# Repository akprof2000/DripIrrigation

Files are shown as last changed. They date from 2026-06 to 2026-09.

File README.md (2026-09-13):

# 🌱 Капельный полив на ESP32










Автономная система капельного полива для дачного участка: 8 независимых каналов, автополив по влажности почвы, учёт расхода воды и контроль засора фильтра. Управление — полностью через Telegram-бота, без облаков и сторонних приложений ([библиотеки Alex Gyver](https://github.com/GyverLibs)).

## 📑 Оглавление

- [Возможности](#возможности)
- [Состав системы](#состав-системы)
  - [Компоненты](#компоненты)
  - [Схема подключения](#схема-подключения)
  - [Распиновка ESP32](#распиновка-esp32)
- [Установка](#установка)
- [Первый запуск](#первый-запуск)
- [Руководство пользователя](#руководство-пользователя)
  - [Команды бота](#команды-бота)
  - [Роли пользователей](#роли-пользователей)
  - [Структура меню](#структура-меню)
  - [Статус системы](#статус-системы)
  - [Типовые сценарии](#типовые-сценарии)
- [Как работает автоматика](#как-работает-автоматика)
- [Данные на SD-карте](#данные-на-sd-карте)
- [Справочник по пунктам меню](#справочник-по-пунктам-меню)
- [Обновление прошивки (OTA)](#обновление-прошивки-ota)
- [Лицензия](#лицензия)

## Возможности

- 🌿 **8 независимых каналов**: клапан + ёмкостный датчик влажности почвы на каждый
- 🤖 **Управление через Telegram** — настройка, статус, отчёты, до 8 пользователей с ролями
- 💧 **Автополив по влажности** с гистерезисом; режимы «всегда ВКЛ», «всегда ВЫКЛ», «авто», «парник»
- 🔧 **Авто-калибровка границ** датчиков: диапазон сам расширяется под реальные условия, разовые выбросы отфильтровываются
- 🌙 **Погодные блокировки**: ночь и дождь (настраиваются)
- 📟 **Датчик потока**: расход за сессию и накопленный итог, текущая скорость в статусе
- 🧽 **Контроль засора фильтра**: тревога в Telegram при падении потока ниже порога
- 💪 **Нагнетательный насос**: пусковой режим + удержание по числу открытых клапанов
- 🗑️ **Пролив дренажа** после простоя, 🚰 **заливка бака** на ночь
- 📊 **Журналы CSV** на SD-карте, графики и отчёты прямо в чате
- 📤 **OTA-обновление** прошивки файлом через Telegram

## Состав системы

### Компоненты

| Компонент | Назначение |
|---|---|
| ESP32 (DevKit) | контроллер |
| SD-карта, модуль 3.3 В | конфигурация, журналы CSV, отчёты |
| Кнопка (подтянута к земле) | сброс настроек |
| Датчик освещённости (дискретный) | определение дня/ночи |
| Датчик дождя (дискретный) | блокировка полива в дождь |
| Датчик потока YF-S201 (~450 имп/л) | учёт расхода и контроль фильтра, ставится на общую магистраль |
| DS3231 (I2C) | часы реального времени, синхронизация с NTP |
| PCF8574 (I2C, адрес 0x20) | расширитель портов для 8 клапанов |
| Релейный модуль, 8 каналов | управление клапанами полива |
| Реле ×3 | нагнетательный насос, налив ёмкости, пролив дренажа |
| 74HC4051 | аналоговый мультиплексор датчиков влажности |
| Ёмкостные датчики влажности ×8 | по одному на канал |

### Плата-носитель

Готовая печатная плата, в которую все модули вставляются в гнёзда, а внешние провода заходят на винтовые
клеммники: [описание платы](docs/hardware-carrier-board.md), [список покупок](docs/bom.md),
[пошаговая сборка](docs/assembly.md). Исходники платы и генератор — в папке `hardware/`.

### Схема подключения

Схема подключения

### Распиновка ESP32

| GPIO | Подключение | GPIO | Подключение |
|---|---|---|---|
| 2 | встроенный светодиод (индикация) | 18 | SD-карта · SCK |
| 4 | датчик освещённости | 19 | SD-карта · MISO |
| 5 | SD-карта · CS | 21 | I2C · SDA (DS3231, PCF8574) |
| 12 | 74HC4051 · S0 | 22 | I2C · SCL (DS3231, PCF8574) |
| 13 | 74HC4051 · S1 | 23 | SD-карта · MOSI |
| 14 | 74HC4051 · S2 | 25 | реле пролива дренажа |
| 15 | датчик дождя | 26 | реле нагнетательного насоса |
| 16 | кнопка сброса настроек | 27 | датчик потока YF-S201 |
| 17 | реле налива ёмкости | 33 | АЦП — сигнал мультиплексора |

## Установка

**Потребуется:** Wi-Fi сеть с выходом в интернет и созданный Telegram-бот ([инструкция по созданию бота](https://kit.alexgyver.ru/tutorials/telegram-basic/)).

1. Соберите схему
2. Скачайте исходники репозитория
3. Токен бота можно задать двумя способами (начиная с v1.8.0):
   - **ничего не делать** — при первом запуске устройство само попросит токен на странице настройки WiFi и сохранит его в EEPROM (так работают готовые бинарники из релизов);
   - **вшить в прошивку** — скопировать `secrets.example.h` в `secrets.h` и вписать токен (файл не коммитится в git).
4. Прошейте ESP32 (Arduino IDE или arduino-cli, плата `esp32`)

> ⚠️ У бота в @BotFather пропишите список команд:
> ```
> reset - сброс состояния
> control - управление поливом
> status - текущий статус
> pause - остановка статусных сообщений
> continue - продолжение получения сообщений
> ```

## Первый запуск

1. **Настройка Wi-Fi.** При первом старте устройство поднимает собственную Wi-Fi точку. Подключитесь к ней — откроется страница настройки: выберите домашнюю сеть, введите пароль и **токен бота** (если он не вшит в прошивку). После сохранения устройство перезагрузится.

   > 🔐 Токен хранится в EEPROM. Если он уже сохранён, поле «Токен» можно оставить пустым — значение не изменится. А если прошивка окажется без токена (например, взята из релизов), устройство при старте поднимет портал **только для его ввода**: сеть, пользователи и калибровки при этом сохраняются, и работа продолжится с того же места.
2. **Регистрация владельца.** Напишите боту кодовое слово со страницы настройки — вы становитесь владельцем устройства.
3. **Базовая настройка** через меню бота:
   - режимы работы клапанов → [сценарий](#типовые-сценарии);
   - калибровка датчиков влажности;
   - названия культур по каналам;
   - пороги срабатывания.
4. Система готова к работе.

> ⚠️ Запомните кодовую фразу со страницы настройки Wi-Fi — без неё не зарегистрироваться владельцем.

> 💡 Сброс к заводским настройкам: зажмите кнопку на 3 секунды сразу после старта и дождитесь трёх коротких миганий светодиода.

## Руководство пользователя

### Команды бота

| Команда | Действие | Кому доступна |
|---|---|---|
| [`/reset`](#reset) | сброс состояния меню, стартовое меню | всем зарегистрированным |
| [`/control`](#controls) | меню управления поливом | всем зарегистрированным |
| [`/status`](#status) | текущий статус системы и датчиков | всем зарегистрированным |
| [`/pause`](#pause) | остановить статусные сообщения | всем зарегистрированным |
| [`/continue`](#continue) | возобновить статусные сообщения | всем зарегистрированным |
| `/register` | запрос на регистрацию | незарегистрированным |

### Роли пользователей

| Роль | Как получить | Что доступно |
|---|---|---|
| 👑 Владелец | первым вводит кодовое слово с портала настройки | всё + OTA-обновление; не может быть понижен или удалён |
| 🎭 Администратор | назначается через «Пользователи → Повышение» | управление, настройка, пользователи, перезагрузка |
| 👤 Пользователь | отправляет `/register`, админ подтверждает | управление поливом, статус, отчёты |

### Структура меню

Пункты с пометкой 👑 видят только администраторы и владелец.

- 👑 [Перезагрузка](#restart)
- 👑 [Пользователи](#users) → [Список](#userslist) · [Повышение](#usersup) · [Понижение](#usersdown) · [Удаление](#usersdel)
- [Управление](#controls)
  - [Режим работы](#working) · [Названия](#naiming) · [Пороги срабатывания](#borders)
  - [Расход воды](#waterflow) · [Пролив дренажа](#spillage) · [Поиск датчика](#search)
- [Статус](#status)
- [Отчёты](#reports)
  - [Графики](#graphics) → [за вчера](#graphystd) · [за сегодня](#graphtd) · [за декаду](#graphdec) · [за период](#graphp) · [за дату](#graphc)
  - [Файл за вчера](#fileystd) · [Файл текущий](#filetd) · [Файл за дату](#filec)
- 👑 [Настройка](#settings)
  - [Работа ночью](#workatnight) · [Работа под дождём](#workatrain)
  - [Дельта влажности](#deltahum) · [Дельта калибровки](#deltacb)
  - [Авто-калибровка без задержки](#autocalnodelay)
  - [Насос давления](#boostpump) · [Порог фильтра](#clogthreshold) · [Фильтр прочищен](#filterclean)
  - [Таймаут Telegram](#tgtimeout)
  - [Калибровка](#calibrate) · [Ручная калибровка](#calibrateManual)
  - [Сброс настроек](#restore) · [Удаление файлов](#filesdel)

### Статус системы

`/status` показывает полную картину одним сообщением:

| Блок | Содержимое |
|---|---|
| 📅 Дата и время | текущее время системы (NTP + RTC) |
| 🌙/☀️ Погода | день или ночь, идёт ли дождь |
| 🌱 По каждому каналу | название культуры, влажность %, порог %, состояние клапана, режим работы (владельцу дополнительно — сырое значение АЦП) |
| 💧 Расход воды | литры за текущую сессию и накопленный итог |
| 🧽 Фильтр | текущая скорость потока, эталон, порог тревоги, состояние (норма/засор) |
| 💪 Насос давления | работает сейчас или нет **и почему** (пусковой режим / порог клапанов / дренаж), текущая настройка |
| 💾 Память | свободная память контроллера |

### Типовые сценарии

<details>
<summary><b>🚿 Настроить автополив канала</b></summary>

1. `Управление → Режим работы` → выбрать клапан → `🤖 АВТО` (или `🏠 А.П.` для парника — поливает и в дождь)
2. `Управление → Пороги срабатывания` → выбрать клапан → ввести порог влажности в %. Клапан откроется при влажности ниже «порог − дельта» и закроется выше «порог + дельта» — [как это работает](#полив-по-влажности)
3. `Управление → Названия` → дать каналу имя культуры («🍅 Томаты»)
</details>

<details>
<summary><b>🔧 Откалибровать датчик влажности</b></summary>

1. `Настройка → Калибровка` → выбрать датчик
2. Опустить датчик в воду → `➡️ ДАЛЕЕ` (это 100 % влажности)
3. Вытереть насухо → `➡️ ДАЛЕЕ` (это 0 %)
4. Установить датчик в почву → `✅ ЗАВЕРШИТЬ`

Если известны точные значения АЦП — `Настройка → Ручная калибровка`, ввести пару `мин,макс`.
</details>

<details>
<summary><b>🔍 Найти датчик, если неизвестен его номер</b></summary>

`Управление → Поиск датчика`: замер в воде, затем насухо — бот назовёт номер датчика с наибольшей разницей показаний.
</details>

<details>
<summary><b>💧 Посмотреть расход воды</b></summary>

`Управление → Расход воды` — литры за текущую сессию полива и накопленный итог, там же кнопка стирания данных. Текущая скорость потока — в `Статусе`.
</details>

<details>
<summary><b>🧽 Пришла тревога «засорился фильтр»</b></summary>

1. Перекройте воду и прочистите фильтр на магистрали
2. `Настройка → Фильтр прочищен` — система заново замерит скорость «чистого» потока

Подробнее о механизме — [Контроль засора фильтра](#учёт-расхода-и-контроль-засора-фильтра).
</details>

<details>
<summary><b>💪 Настроить насос повышения давления</b></summary>

`Настройка → Насос давления`:
- число **1–8** — держать насос включённым, пока открыто столько клапанов и больше;
- **9** — не держать, только пусковые 30 секунд при каждом открытии клапана.

Текущее состояние насоса и причина — в `Статусе`. [Диаграмма работы](#насос-повышения-давления).
</details>

<details>
<summary><b>📈 Получить графики и файлы измерений</b></summary>

`Отчёты → Графики` — график влажности по каналам за вчера/сегодня/декаду/период/дату.
`Отчёты → Файл...` — бот пришлёт CSV-файл с измерениями ([формат](#данные-на-sd-карте)).
</details>

<details>
<summary><b>🔕 Отключить уведомления на время</b></summary>

Команда `/pause`, вернуть — `/continue` (действует до перезагрузки устройства).
</details>

<details>
<summary><b>👥 Добавить нового пользователя</b></summary>

1. Новый человек пишет боту `/register`
2. Администраторам приходит запрос со ссылкой-командой — админ нажимает её, человек зарегистрирован как «пользователь»
3. При необходимости повысить: `Пользователи → Повышение`
</details>

<details>
<summary><b>📤 Обновить прошивку по воздуху</b></summary>

Владелец отправляет в чат файл `DripIrrigation.ino.bin` — устройство обновится и перезагрузится. [Подробнее](#обновление-прошивки-ota).
</details>

## Как работает автоматика

Общая картина: раз в минуту выполняется цикл полива, а фоновые задачи (бот, насос, контроль потока, дренаж, связь) работают непрерывно.

Алгоритм работы

### Полив по влажности

Раз в минуту система опрашивает все 8 датчиков (медиана из 9 замеров АЦП — устойчиво к помехам) и для каждого канала в режиме «авто» сравнивает влажность с порогом. Гистерезис (зона ±Δ вокруг порога) исключает дребезг — клапан не щёлкает туда-сюда при колебаниях показаний:

Автополив с гистерезисом

### Авто-калибровка границ

Со временем реальный диапазон датчика уходит за границы, заданные при калибровке: почва после ливня оказывается влажнее «воды» из стакана, а в засуху — суше «сухого» замера. Тогда проценты упираются в 0 или 100 и перестают что-либо показывать.

Система расширяет границы сама: если показание вышло за границу, она отодвигается до этого значения **с запасом в дельту калибровки**. Границы только расширяются, сужения нет — сузить можно лишь перекалибровкой.

Авто-калибровка границ

Два предохранителя:

- **Разовые выбросы игнорируются.** Граница двигается, только если превышение держится **3 минутных замера подряд**. Один сбойный отсчёт АЦП (наводка, плохой контакт) обнуляет счётчик и ничего не портит. Внутри окна подтверждения берётся самое мягкое из превышений, чтобы выброс не утянул границу. Отключается настройкой [«Авто-калибровка без задержки»](#autocalnodelay).
- **Во время калибровки функция выключена.** Пока открыт диалог калибровки или поиска датчика, датчик держат в воде или на воздухе — такие показания нельзя принимать за рабочие, иначе система «выучит» калибровочные экстремумы как норму.

Новые границы сохраняются на SD-карту автоматически.

### Аварийный режим при неисправном оборудовании

Платы (RTC, SD-карта, расширитель клапанов PCF8574) инициализируются **неблокирующе**: если узел не отвечает, система всё равно завершает загрузку и поднимает бота. Неисправность приходит в чат с пояснением последствий — не нужно ехать к устройству и подключаться кабелем, чтобы понять, что случилось.

Пока неисправность не устранена:

- **полив остановлен** — работать с неисправным железом опасно;
- насос, дренаж и залив бака **выключены напрямую по пинам** (не через возможно мёртвый PCF8574);
- интерфейс бота свёрнут до отчёта и **единственной кнопки «Перезагрузка»** — починив контакт, систему можно поднять прямо из чата.

### Погодные блокировки

Ночью и в дождь полив останавливается, если это запрещено в настройках. Исключения: каналы «всегда ВКЛ» и режим «парник» продолжают полив под дождём (но не ночью). При наступлении ночи подаётся сигнал заполнения ёмкости — за ночь вода прогреется к утреннему поливу.

### Насос повышения давления

При открытии любого клапана насос включается минимум на 30 секунд для стабилизации давления. Дальше — по настройке: либо выключается, либо продолжает работать, пока открыто N и более клапанов:

Работа насоса

Пролив дренажа также идёт с включённым насосом. Фактическое состояние насоса и причина всегда видны в `Статусе`.

### Пролив дренажа

Если полив не шёл более 5 часов, при открытии первого клапана автоматически запускается пролив дренажа на 12 секунд — сброс накопившейся ржавчины из труб, чтобы не засорялись форсунки. Ручной запуск: `Управление → Пролив дренажа`.

### Учёт расхода и контроль засора фильтра

На общей магистрали стоит импульсный датчик потока (YF-S201). Система считает расход за сессию полива и накопленный итог, а также непрерывно следит за скоростью потока:

Контроль засора фильтра

Ключевые детали алгоритма:

- после открытия клапана трубы наполняются — поток кратковременно завышен, поэтому система **дожидается стабилизации** и только потом замеряет;
- эталон «чистого» фильтра запоминается автоматически (разовые выбросы отфильтровываются — новое значение должно продержаться несколько минут);
- замеры при работающем пусковом насосе и заливке бака не учитываются;
- тревога подтверждается несколькими окнами замера подряд и повторяется не чаще раза в сутки.

## Данные на SD-карте

```
/configuration.dat      — конфигурация системы (бинарная)
/ГГГГ/ММ/ДД.csv         — журнал измерений за день
```

Каждую минуту в CSV дописывается по строке на канал:

| Колонка | Описание |
|---|---|
| `UnixTime` | метка времени UNIX |
| `DateTime` | дата и время в читаемом виде |
| `Index` | номер канала (1–8) |
| `Title` | название культуры |
| `Humidity` | влажность, % |
| `Valve` | состояние клапана: 1 — открыт, 0 — закрыт |
| `Border` | порог срабатывания, % |
| `Night` | ночь: 1/0 |
| `Rain` | дождь: 1/0 |

Файлы за прошлые годы можно удалить из бота: `Настройка → Удаление файлов`.

## Справочник по пунктам меню

#### /reset — сброс состояния
Сбрасывает состояние меню и выводит стартовое меню

#### /status · меню «Статус»
Полный статус системы — [расшифровка блоков](#статус-системы)

#### /pause — остановка статусных сообщений
Останавливает сообщения о событиях на устройстве (действует до перезагрузки)

#### /continue — продолжение получения сообщений
Возобновляет сообщения о событиях

#### 👑 Перезагрузка
Перезапускает устройство (с подтверждением)

#### 👑 Пользователи

- **Список** — зарегистрированные пользователи (идентификаторы и роли)
- **Повышение** — Пользователь → Администратор
- **Понижение** — Администратор → Пользователь (владельца понизить нельзя)
- **Удаление** — удаление пользователя (владельца удалить нельзя)

#### Управление

- **Режим работы** — режим каждого клапана: ✅ постоянно включен · ⛔ постоянно выключен · 🤖 автоматический по влажности · 🏠 парник (авто, работает и при дожде); кнопка «Установить для всех»
- **Названия** — имя выращиваемой культуры для каждого канала
- **Пороги срабатывания** — порог влажности каждого клапана в %
- **Расход воды** — литры за сессию и накопленный итог; стирание данных
- **Пролив дренажа** — ручной запуск пролива (12 секунд)
- **Поиск датчика** — определить номер датчика по замерам в воде и насухо

#### Отчёты

- **Графики**
  - **за вчера** — почасовой график влажности по каналам
  - **за сегодня** — почасовой график за текущий день
  - **за декаду** — последние 10 дней, 6 значений в сутки
  - **за период** — от 1 до 60 дней, `целое(60 / кол-во дней)` значений в сутки
  - **за дату** — график за выбранный день
- **Файл за вчера** — CSV-файл с измерениями за вчера
- **Файл текущий** — CSV-файл за сегодня
- **Файл за дату** — CSV-файл за выбранный день

#### 👑 Настройка

- **Работа ночью** — разрешить/запретить полив ночью
- **Работа под дождём** — разрешить/запретить полив в дождь
- **Дельта влажности** — половина гистерезиса вокруг порога, % (0–100, по умолчанию 5)
- **Дельта калибровки** — запас у границ калибровки датчиков, ед. АЦП (0–2048, по умолчанию 15). Используется и как запас при [авто-калибровке границ](#авто-калибровка-границ)
- **Авто-калибровка без задержки** — двигать границу сразу по первому замеру за ней. По умолчанию **выключено**: граница двигается, только если превышение держится 3 замера подряд (3 мин) — так одиночный выброс АЦП не портит калибровку. Включайте, только если нужна мгновенная реакция
- **Насос давления** — держать насос при ≥ N открытых клапанах (1–8); 9 — только пусковые 30 с
- **Порог фильтра** — % от скорости «чистого» фильтра, ниже которого тревога (10–90, по умолчанию 50)
- **Фильтр прочищен** — сброс эталона после чистки, система замерит его заново
- **Таймаут Telegram** — через сколько секунд без связи считать её потерянной (120–3600, по умолчанию 180). Увеличьте, если приходит много сообщений о кратковременных обрывах связи
- **Калибровка** — пошаговая калибровка датчика: замер в воде, затем насухо
- **Ручная калибровка** — ввод граничных значений АЦП парой `мин,макс`
- **Сброс настроек** — возврат к заводским установкам
- **Удаление файлов** — удаление архивов измерений за прошлые годы

## Обновление прошивки (OTA)

1. Возьмите готовый файл со [страницы релизов](https://github.com/akprof2000/DripIrrigation/releases) (собирается автоматически в GitHub Actions) — или соберите сами (`Скетч → Экспорт бинарного файла` в Arduino IDE):
   - `DripIrrigation.ino.bin` — обычный (~1.3 МБ);
   - `DripIrrigation.ino.bin.gz` — сжатый (~0.8 МБ), удобнее по мобильному интернету — устройство распакует его само.
2. Отправьте файл в чат боту **от имени владельца**
3. Устройство скачает файл, обновится и перезагрузится; после старта придёт сообщение «🚀 Система запущена! Прошивка vX.Y.Z»

> 💡 Имя файла может содержать суффикс копии, который добавляет Windows при повторном скачивании: `DripIrrigation.ino.bin (2).gz` и `DripIrrigation.ino (2).bin` тоже принимаются — переименовывать не нужно.

> 🔁 Если пришло `OTA Fetch Error` — файл не удалось **скачать** (обычно не хватило памяти на защищённое соединение после долгой работы). Прошивка при этом не пострадала: просто отправьте файл ещё раз, а если повторяется — перезагрузите систему через меню и повторите.

> ✅ Проверить версию можно в любой момент — она указана в шапке `/status`. Если после OTA номер не изменился, обновление не применилось.

> 🛡️ OTA безопасен: прошивка пишется в неактивный раздел, загрузка переключается только при валидном образе. Неудачное обновление оставит устройство на прежней прошивке (не «кирпич»).

> ⚠️ Прошивка должна быть собрана под ту же схему разделов (partition scheme), что и установленная.

> 🏷️ Версия задаётся в `version.h` (`FW_VERSION`) и должна совпадать с git-тегом релиза.

## Сторонние компоненты

- Библиотеки [Alex Gyver](https://github.com/GyverLibs): FastBot2, GyverNTP, GyverDS3231, FileData, CharDisplay и зависимости
- [uzlib](https://github.com/pfalcon/uzlib) (zlib-лицензия) — потоковая распаковка gzip для OTA из `.gz` (файлы `uzlib.h`, `tinflate.c`, `tinfgzip.c`, `crc32.c`, `adler32.c` и заголовки)
- PCF8574 library (Renzo Mischianti)

## Лицензия

[WTFPL 2.0](LICENSE) — делайте с этим кодом что хотите, без каких-либо условий.

Исключение: файлы `uzlib.h`, `tinflate.c`, `tinfgzip.c`, `crc32.c`, `adler32.c`,
`defl_static.h`, `tinf.h`, `tinf_compat.h`, `uzlib_conf.h` — это стороннее
заимствование ([uzlib](https://github.com/pfalcon/uzlib)) и они остаются под
своей zlib-лицензией; уведомления об авторстве в них сохранены.

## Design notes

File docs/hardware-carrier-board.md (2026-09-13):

# 🧩 Плата-носитель DripIrrigation

Контроллер собирается «из кубиков»: все сложные узлы покупные, а связывает их **одна плата-носитель**,
в которую модули **вставляются в гнёзда**. На плате нет SMD, нет проводов «навесом», и ничего не отваливается:
модули сидят в гнёздах и прижаты стойками, все внешние провода — в винтовых клеммниках с обжатыми
наконечниками, в том числе провода к релейным модулям.

Плата **уже спроектирована**: файл [`hardware/DripCarrier.kicad_pcb`](../hardware/DripCarrier.kicad_pcb)
проверен DRC в KiCad 10: ошибок и неразведённых цепей нет. Раздел [5](#5-заказ-платы) — как заказать.

Распиновка ESP32 — из `pins.h` / README, без изменений.

Полный список покупок со ссылками — [bom.md](bom.md). Пошаговая сборка с картинками — [assembly.md](assembly.md).

---

## 1. Из чего состоит

Структура

### Выбранные модули

| Что | Какой именно | Куда ставится |
|---|---|---|
| ESP32 | DevKitC **38 pin**, Type-C, CP2102, вариант ESP-32U | гнездо U1 (2 гребёнки 1×19) |
| Часы | модуль DS3231 с держателем батарейки, выводы 32K · SQW · SCL · SDA · VCC · GND | гнездо J9 (1×6) |
| SD-карта | шилд Micro SD формата D1 mini, два ряда по 8 выводов | гнездо J8 (2×8) |
| Реле клапанов | красный модуль H/L, **8 каналов, 5 В**, 108,5×50 мм | клеммы J6 |
| Реле насоса | красный модуль H/L, **1 канал, 5 В**, 51×25,5 мм | клеммы J7 |
| Реле налива и дренажа | красный модуль H/L, **2 канала, 5 В** | клеммы J5 |
| Датчик света | модуль фоторезистора на LM393, выход DO; фоторезистор выпаян и вынесен наружу | гнездо U6 (1×3), фоторезистор на клеммник J12 |
| Датчики влажности ×8 | ёмкостные Capacitive Soil Moisture Sensor v2.0, кабель 3 провода | клеммники S1…S8 |

### Остальное

| Что | Что искать в магазине | Куда ставится |
|---|---|---|
| PCF8574P (микросхема DIP-16) | `PCF8574P DIP` | панелька U4 |
| 74HC4051 (микросхема DIP-16) | `CD74HC4051E DIP` / `SN74HC4051N` | панелька U5 |
| Импульсный DC-DC 12→5 В, 2 А, формат TO-220 | `K7805-2000R3` (3 pin: IN GND OUT) | U2 |
| Импульсный DC-DC 5→3,3 В, 1 А, формат TO-220 | `K7803-1000R3` (3 pin: IN GND OUT) | U3 |
| Антенна 2,4 ГГц с кабелем IPEX | `2.4G antenna IPEX u.FL` | к ESP-32U, выводится из корпуса |
| Датчик дождя Rain Seer, проводной, с сухим контактом | [товар](https://aliexpress.ru/item/1005004442230539.html?sku_id=12000029194430427) | клеммник J11 (2 провода) |
| Расходомер | `YF-S201` | клеммник J10 |
| Источник питания 12 В, не менее 5 А | любой источник постоянного тока 12 В | клеммник J1 |

### Замечания по выбранным модулям

* **ESP-32U** без встроенной антенны, у неё разъём IPEX. Без внешней антенны Wi-Fi почти не работает.
  Зато антенну можно вывести наружу корпуса, подальше от реле, и связь на участке будет лучше.
* **Ряды ESP32 38 pin** на плате разнесены на 25,4 мм. Перед заказом платы измерьте свой модуль штангенциркулем.
* **DS3231** у этого продавца, по отзывам, может прийти в варианте DS3231M. Он чуть менее точный, но часы
  всё равно синхронизируются по NTP, так что это не важно.
* **Угловые штыри у DS3231 и датчика света** нужно заменить прямыми. Модули лежат параллельно плате над
  своими гнёздами J9 и U6, штыри смотрят вниз. Выпаяйте угловую гребёнку и впаяйте прямую той же длины со
  стороны деталей модуля так, чтобы штыри выходили с обратной стороны. Если оставить угловые штыри, модуль
  встанет вертикально, будет качаться и не поместится под крышку.
* **SD-шилд D1 mini** сидит на 16 выводах и держится в гнезде крепче маленьких 6-контактных модулей.
  Используются только D5 (SCK), D6 (MISO), D7 (MOSI), D8 (CS), 3V3 и G.
* **Датчики влажности** бывают с микросхемой TLC555 и с NE555. Посмотрите маркировку восьминогой
  микросхемы на каждом датчике. TLC555 работает от 3,3 В. NE555 от 3,3 В не запускается и выдаёт 0 В,
  таким датчикам нужно 5 В. Питание всех восьми датчиков выбирается перемычкой **JP1** на плате:
  джампер на 3V3 или на 5V. Выход датчика даже при 5 В не превышает примерно 3 В, АЦП ESP32 это выдерживает.
  Не смешивайте на одной плате датчики с разными микросхемами. После смены питания датчики нужно
  перекалибровать.
* **Датчик света** стоит на плате в гнезде U6, а наружу выносится только фоторезистор. Как подготовить модуль:
  1. Выпаять фоторезистор с модуля.
  2. В освободившиеся отверстия впаять два штырька 2,54 мм.
  3. Соединить эти штырьки со штырьками JL1 на плате коротким кабелем на два провода с колодками на концах.
  4. Выносной фоторезистор подключить двумя проводами к клеммнику J12. Выводы фоторезистора закрыть термоусадкой.

  Порядок выводов гнезда U6 рассчитан на VCC · GND · DO. Сверьте с подписями на своём модуле перед пайкой гнезда.
* **Датчик дождя** механический: шайбы набухают от воды и переключают контакт. Для платы это кнопка на двух
  проводах, клеммник J11. Резистор R7 10 кОм подтягивает вход GPIO15 к 3,3 В, R8 1 кОм и конденсатор C4 100 нФ
  защищают вход от наводок на длинном кабеле. Прошивка считает дождём низкий уровень, поэтому контакт
  должен **замыкаться при дожде**. Проверьте мультиметром до подключения: сухой датчик — контакт разомкнут,
  датчик с мокрыми шайбами — замкнут. Если у датчика три провода, используйте общий и нормально разомкнутый.
  Если контакт работает наоборот, скажите: поменяю логику в прошивке.
* **PCF8574 и 74HC4051 взяты микросхемами**: у модулей разных продавцов разный порядок выводов,
  а у DIP-микросхемы он стандартный.

> ⚠️ Подписи выводов ESP32, SD-шилда и DS3231 нанесены на шелкографию платы. Перед пайкой гнёзд
> приложите свои модули и сверьте подписи — у клонов бывает зеркальный порядок.

---

## 2. Питание и реле

Питание

* Три шины: **12 В** (клапаны, насос, вход DC-DC), **5 В** (ESP32, все реле, расходомер),
  **3,3 В** (логика и датчики).
* На входе — предохранитель F1 5 А и P-MOSFET Q1 от переполюсовки. Насос — через отдельный F2 3 А.
  MOSFET вместо диода взят из-за тока: при 4–5 А диод Шоттки терял бы около 3 Вт и требовал радиатор,
  а на канале IRF4905 теряется 0,5 Вт, и клапаны получают полные 12 В. TVS-диод D2 на шине 12 В гасит
  выбросы от катушек клапанов и насоса при размыкании реле.
* Дорожки 12 В шириной 2 мм (до 5 А), 5 В — 1,2 мм, земля — 1 мм плюс сплошная заливка на нижней стороне.
* Вывод 3V3 модуля ESP32 к плате **не подключён**: свой стабилизатор модуля питает только ESP32,
  а вся периферия — от U3. Два стабилизатора на одной шине мешали бы друг другу.
* Каждый релейный модуль получает +5 В и GND со своей клеммы на плате. Одиннадцать катушек по 70 мА
  плюс ESP32 дают до 1,2 А, поэтому преобразователь 12→5 В нужен не слабее 2 А.
* **Преобразователи U2 и U3 — только импульсные** (K7805-2000R3 и K7803-1000R3). У них КПД около 90%:
  на 12→5 В при 1,2 А теряется меньше 1 Вт, радиатор не нужен. Линейный L7805 в таком же корпусе при том же
  токе рассеивал бы около 8 Вт и без большого радиатора перегрелся бы — его ставить нельзя.
* Силовые провода клапанов и насоса идут **к контактам реле**, а не через плату. Плата отдаёт на них
  +12 В с клеммников J3 (общая шина COM клапанов) и J4 (насос, после F2).

### Перемычки H/L на реле

Уровень включения задан прошивкой, поэтому перемычки ставятся так:

| Модуль | Чем управляется | Как включает прошивка | Перемычка |
|---|---|---|---|
| 8 каналов, клапаны | PCF8574, выходы P0…P7 | низким уровнем | **L** |
| 1 канал, насос | ESP32 GPIO26 | высоким уровнем | **H** |
| 2 канала, налив и дренаж | ESP32 GPIO17 и GPIO25 | высоким уровнем | **H** |

**Клапаны в режиме L работают надёжно.** PCF8574 хорошо тянет выход к земле, а в выключенном состоянии
почти не отдаёт ток, так что реле не срабатывает ложно. При включении питания PCF8574 держит выходы
в единице, клапаны закрыты.

**Насос, налив и дренаж в режиме H нужно проверить до сборки.** Модуль рассчитан на сигнал 5 В, а ESP32
выдаёт 3,3 В. Многие экземпляры срабатывают и так, но не все. Проверка занимает минуту:
подайте на модуль 5 В, перемычку поставьте в H, а на вход IN подайте 3,3 В с платы ESP32.
Реле должно щёлкнуть.

Если реле от 3,3 В не срабатывает, есть два выхода:

1. Перевести перемычку в **L** и инвертировать в прошивке управление насосом, наливом и дренажом.
   В режиме L 3,3 В на входе реле надёжно выключает, а 0 В надёжно включает.
2. Взять эти модули в варианте **12 В**: вход в режиме H у них тоже рассчитан на логику, но питание
   катушек идёт от 12 В и разгружает шину 5 В. Проверять срабатывание от 3,3 В всё равно нужно.

---

## 3. Плата

Двухсторонняя, 150×110 мм, все детали выводные. Сгенерирована скриптом
[`hardware/gen_pcb.py`](../hardware/gen_pcb.py), который расставляет компоненты, проверяет, что корпуса
не пересекаются, задаёт цепи и трассирует дорожки. Верх — дорожки в основном горизонтальные,
низ — вертикальные, снизу ещё заливка земли.

**Все детали ставятся на верхнюю сторону и паяются только с нижней.** Переворачивать плату в процессе
сборки не нужно.

**Расстановка сделана под монтаж проводов:**

* Все клеммники стоят по краям платы: сверху питание 12 В и управление реле, справа расходомер, свет и дождь,
  снизу датчики влажности. Ставьте клеммники отверстием для провода наружу, к краю платы.
* Высокие детали — предохранители, конденсаторы, модули DC-DC — стоят вторым рядом, внутри платы.
  Они не мешают заводить провода и крутить винты.
* Проверка пересечений учитывает реальные размеры модулей, а не только их гребёнки. Модуль DS3231
  размером около 38×22 мм показан на плате пунктиром и не накрывает соседние детали. Перед заказом
  измерьте свой модуль: если он крупнее, его контур нужно поправить в генераторе.

Верх

Низ

### Разъёмы к реле

У каждого релейного модуля своя клеммная колодка: питание +5 В, земля и его сигналы. Питание не
передаётся с модуля на модуль, поэтому отключение одного не обесточивает другие.

| Клеммник | Модуль | 1 | 2 | 3 | 4 | 5…10 |
|---|---|---|---|---|---|---|
| J6, 10P | реле 8 каналов | +5 В → DC+ | GND → DC− | IN1 | IN2 | IN3…IN8 |
| J7, 3P | реле 1 канал | +5 В → DC+ | GND → DC− | насос → IN | — | — |
| J5, 4P | реле 2 канала | +5 В → DC+ | GND → DC− | налив → IN1 | дренаж → IN2 | — |

### Что куда подключается

**Питание платы — клеммник J1 в левом верхнем углу.** Источник 12 В, не менее 5 А. Контакт с квадратной
площадкой — **+12 В**, второй — **GND (минус)**. Перепутанная полярность не сожжёт плату: MOSFET Q1 просто не
откроется, и плата не включится.

**Клеммники — внешние провода**

| Обозначение | Подпись на плате | Контакты по порядку, от квадратной площадки | Что подключается |
|---|---|---|---|
| J1 | 12V IN | +12 В · GND | источник питания 12 В, 5 А |
| J3 | 12V VALVES | +12 В · GND | +12 В на общий COM всех 8 реле клапанов; GND — к второму проводу клапанов |
| J4 | 12V PUMP | +12 В (после F2) · GND | +12 В на COM реле насоса; GND — к насосу |
| J6 | RELAY 8 | +5 В · GND · IN1 … IN8 | модуль реле 8 каналов: DC+, DC−, входы IN1…IN8 |
| J7 | RELAY 1 | +5 В · GND · PUMP | модуль реле 1 канал: DC+, DC−, IN |
| J5 | RELAY 2 | +5 В · GND · FILL · DRAIN | модуль реле 2 канала: DC+, DC−, IN1 налив, IN2 дренаж |
| J10 | FLOW | +5 В · GND · сигнал | расходомер YF-S201: красный, чёрный, жёлтый |
| J12 | LDR | вывод 1 · вывод 2 | выносной фоторезистор, полярности нет |
| J11 | RAIN SW | сигнал · GND | датчик дождя, сухой контакт: общий и нормально разомкнутый провод |
| S1 … S8 | SOIL 1 … 8 | питание · GND · сигнал | датчики влажности: VCC, GND, AOUT |

Питание датчиков влажности на S1…S8 — 3,3 или 5 В, выбирается джампером JP1.

**Гнёзда и панельки — модули и микросхемы**

| Обозначение | Что вставляется |
|---|---|
| U1 | ESP32 DevKitC 38 pin, USB вниз |
| J8 | шилд microSD D1 mini |
| J9 | модуль часов DS3231 |
| U6 | модуль датчика света LM393 |
| U4 | микросхема PCF8574P |
| U5 | микросхема 74HC4051 |
| U2 | импульсный DC-DC 12→5 В |
| U3 | импульсный DC-DC 5→3,3 В |

**Остальные детали на плате**

| Обозначение | Деталь | Назначение |
|---|---|---|
| F1 | предохранитель 5 А | защита всего питания 12 В |
| F2 | предохранитель 3 А | защита цепи насоса |
| Q1 | P-MOSFET IRF4905 | защита от переполюсовки, без падения напряжения |
| R9 | 10 кОм | затвор Q1 к земле |
| D2 | TVS P6KE18CA | гасит выбросы на шине 12 В |
| C5, C6 | 100 нФ | развязка PCF8574 и 74HC4051 |
| R10, R11 | 4,7 кОм | подтяжки I2C, шина работает и без модуля часов |
| C1 | 1000 мкФ | фильтр 12 В |
| C2, C3 | 100 мкФ | фильтры 5 В и 3,3 В |
| C4 | 100 нФ | фильтр входа датчика дождя |
| R1, R2, R3 | 10 кОм | подтяжка выбора канала мультиплексора |
| R4 | 10 кОм | подтяжка кнопки к земле; кнопка замыкает вход на 3,3 В |
| R5, R6 | 10 кОм, 33 кОм | делитель сигнала расходомера: с внутренней подтяжкой 10 кОм в YF-S201 даёт около 3,1 В |
| R7 | 10 кОм | подтяжка датчика дождя |
| R8 | 1 кОм | защита входа датчика дождя |
| SW1 | кнопка | сброс настроек: замыкает GPIO16 на 3,3 В, как в прошивке |
| JP1 | штыри 1×3 и джампер | питание датчиков влажности: 3V3 или 5V |
| JL1 | штыри 1×2 | кабель к площадкам фоторезистора на модуле U6 |

### Диаметры отверстий

Отверстия подобраны под выводы деталей с запасом 0,2–0,4 мм. Таблица диаметров нанесена на шелкографию
платы слева внизу, под ESP32.

| Детали | Вывод детали | Отверстие | Площадка |
|---|---|---|---|
| Клеммники 5,08 мм, все | около 1,0 мм | **1,3 мм** | 2,6 мм |
| Держатели предохранителей F1, F2 | плоский, до 1,2 мм | **1,5 мм** | 2,8 мм |
| TVS P6KE18CA (D2) | до 1,0 мм | **1,5 мм** | 2,8 мм |
| MOSFET Q1, выводы разведены на 5,08 мм | 0,9 мм | 1,1 мм | 2,0 мм |
| Гнёзда модулей ESP32, SD, DS3231, свет; штыри JP1, JL1 | 0,64 мм квадрат | 1,0 мм | 1,6 мм |
| DC-DC U2, U3, штыри | до 0,8 мм | 1,0 мм | 1,6 мм |
| Кнопка SW1 | 0,7 мм плоский | 1,0 мм | 1,7 мм |
| Конденсатор 1000 мкФ (C1) | 0,6 мм | 1,1 мм | 2,0 мм |
| Панельки DIP-16, конденсаторы 100 мкФ | 0,5 мм | 0,9 мм | 1,6–1,7 мм |
| Резисторы, керамические C4, C5, C6 | 0,6 мм | 0,8 мм | 1,6 мм |
| Крепёжные отверстия М3 | — | 3,2 мм, без металлизации | — |

Перед пайкой сверьте с реальными деталями: вывод держателя предохранителя и диода штангенциркулем.

### Что паяется

| Поз. | Деталь | Что искать | Кол-во |
|---|---|---|---|
| U1 | гребёнка-мама 1×19, machined | `machined female header 2.54 1x20` (отрезать) | 2 |
| J8 | гребёнка-мама 1×8 | `female header 2.54 1x8` | 2 |
| J9 | гребёнка-мама 1×6 | `female header 2.54 1x6` | 1 |
| U6 | гребёнка-мама 1×3 под модуль датчика света | `female header 2.54 1x3` | 1 |
| JL1 | штыри 1×2 к площадкам фоторезистора модуля | `pin header 2.54` | 1 |
| U4, U5 | панелька DIP-16 | `DIP-16 IC socket` | 2 |
| J1, J3, J4, J11, J12 | клеммник 5,08 мм 2P | `KF301-2P` или разъёмный `KF2EDG 5.08 2P` | 5 |
| J6 | клеммник 5,08 мм 10P | `KF2EDG 5.08 10P` (или 5 шт. 2P в ряд) | 1 |
| J5 | клеммник 5,08 мм 4P | `KF2EDG 5.08 4P` | 1 |
| J7, J10, S1–S8 | клеммник 5,08 мм 3P | `KF301-3P` / `KF2EDG 5.08 3P` | 10 |
| R7 | 10 кОм 0,25 Вт, подтяжка входа датчика дождя | | 1 |
| R8 | 1 кОм 0,25 Вт, защита входа датчика дождя | | 1 |
| C4 | 100 нФ керамический, шаг 5 мм | | 1 |
| F1, F2 | держатель предохранителя 5×20 + вставки 5 А, 3 А | `5x20 PCB fuse holder` | 2 |
| Q1 | P-MOSFET 55 В 74 А, TO-220 | `IRF4905` | 1 |
| D2 | TVS двунаправленный 18 В, 600 Вт | `P6KE18CA` | 1 |
| C1 | 1000 мкФ 16 В, шаг 5 мм | | 1 |
| C2, C3 | 100 мкФ 16 В, шаг 2,5 мм | | 2 |
| R1–R4, R9 | 10 кОм 0,25 Вт (подтяжки S0…S2, кнопки и затвора Q1 вниз) | | 5 |
| R10, R11 | 4,7 кОм 0,25 Вт (подтяжки I2C) | | 2 |
| C5, C6 | 100 нФ керамика, шаг 5 мм (развязка) | | 2 |
| R5, R6 | 10 кОм и 33 кОм (делитель расходомера) | | 1+1 |
| SW1 | кнопка тактовая 6×6 | | 1 |
| JP1 | штыри 1×3 + джампер (питание датчиков влажности 3,3 / 5 В) | `pin header 2.54 1x3` + `jumper cap` | 1 |
| — | стойки М3 пластик 10 мм, винты | | 16 |

Полная таблица цепей — [`hardware/netlist.md`](../hardware/netlist.md).

### Цепи, которые легко упустить

* GPIO12 (S0 мультиплексора) — strapping-пин ESP32, при старте должен быть низким: R1…R3 тянут S0…S2 к земле.
* Выход YF-S201 пятивольтовый и внутри подтянут к 5 В резистором 10 кОм: вместе с R5/R6 на GPIO27 получается
  около 3,1 В. Если у вашего экземпляра расходомера на выходе меньше 2,6 В, замените R6 на 10 кОм к 3,3 В.
* PCF8574: A0…A2 на GND → адрес 0x20, как в прошивке. 74HC4051: E и VEE на GND.
* На DS3231 и модулях датчиков подтяжки I2C и компараторы уже есть — на плате их нет специально.

---

## 4. Компоновка в корпусе

Корпус

* Корпус `ABS junction box 250×200×80 IP65`. Плата и все три релейных модуля на стойках М3.
* Провода от J5, J6 и J7 к реле обжаты наконечниками НШВИ и зажаты винтами с обеих сторон.
  Если у 8-канального модуля вход сделан гребёнкой, а не клеммами, используйте одну колодку 1×10
  с обжатыми контактами, а не десять отдельных проводов.
* Ввод кабелей — гермовводы PG9; концы проводов обжаты наконечниками НШВИ (клещи `HSC8 6-4`).
* Антенна ESP-32U выводится через стенку корпуса разъёмом SMA.

---

## 5. Заказ платы

Файлы для завода собираются одной командой через KiCad 10 в Docker. Скрипт заливает землю, прогоняет DRC
и складывает Gerber-файлы со сверловкой в архив `hardware/DripCarrier-gerbers.zip`.

```bash
bash hardware/kicad-docker.sh
```

Этот архив загружается на JLCPCB или PCBWay: 2 слоя, толщина 1,6 мм, 5 штук. Стоит около 5–10 $ плюс доставка.

Хотите поменять расположение — правьте координаты в `hardware/gen_pcb.py` и запускайте его снова.
Он проверит пересечения, перетрассирует плату и обновит картинки. После этого снова запустите скрипт Docker.

```bash
python hardware/gen_pcb.py
```

---

## 6. Сборка и проверка

1. Проверить реле насоса, налива и дренажа на срабатывание от 3,3 В, как описано в разделе 2.
2. Впаять клеммники, гнёзда, панельки, резисторы, диод, конденсаторы, держатели предохранителей, кнопку.
   Модули пока не вставлять.
3. Подать 12 В на J1. Проверить: +12 на J3, 5,0 В между контактами 1 и 2 клеммника J6,
   3,3 В на выводе 16 панельки U4.
4. Вставить ESP32 с антенной, прошить, дождаться Wi-Fi.
5. Вставить PCF8574, 74HC4051, DS3231, SD — в логе прошивки должны появиться RTC и расширитель.
6. Выставить перемычки H/L, подключить реле 8 каналов к J6, 1 канал к J7, 2 канала к J5, щёлкать каналами из меню бота.
7. Обжать и подключить датчики и клапаны, откалибровать датчики влажности.

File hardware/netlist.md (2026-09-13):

# Таблица цепей платы-носителя

Сгенерировано `gen_pcb.py`. Формат: `Компонент.пин`.

| Цепь | Выводы |
|---|---|
| `+12V` | J3.1, Q1.3, D2.1, C1.1, U2.1, F2.1 |
| `+3V3` | U3.3, C3.1, U4.16, U5.16, J8.3V3, J9.5, SW1.3, SW1.4, C5.1, C6.1, R10.2, R11.2, JP1.1, U6.1, R7.2 |
| `+5V` | J6.1, J7.1, J5.1, U2.3, C2.1, U3.1, U1.5V, JP1.3, J10.1 |
| `12V_F` | F1.2, Q1.2 |
| `12V_PUMP` | J4.1, F2.2 |
| `12V_RAW` | J1.1, F1.1 |
| `GND` | J1.2, J3.2, J4.2, J6.2, J7.2, J5.2, R9.2, D2.2, C1.2, U2.2, C2.2, U3.2, C3.2, U1.GND, U1.GND2, U1.GND3, U4.1, U4.2, U4.3, U4.8, U5.6, U5.7, U5.8, J8.G, J9.6, R4.2, R1.2, R2.2, R3.2, R6.2, C5.2, C6.2, J10.2, U6.2, J11.2, C4.2, S1.2, S2.2, S3.2, S4.2, S5.2, S6.2, S7.2, S8.2 |
| `SENS_V` | JP1.2, S1.1, S2.1, S3.1, S4.1, S5.1, S6.1, S7.1, S8.1 |
| `ADC` | U1.D33, U5.3 |
| `BTN` | U1.D16, SW1.1, SW1.2, R4.1 |
| `DRAIN` | J5.4, U1.D25 |
| `FILL` | J5.3, U1.D17 |
| `FLOW` | U1.D27, R5.2, R6.1 |
| `FLOW_IN` | R5.1, J10.3 |
| `LDR_A` | J12.1, JL1.1 |
| `LDR_B` | J12.2, JL1.2 |
| `LIGHT` | U1.D4, U6.3 |
| `P0` | J6.3, U4.4 |
| `P1` | J6.4, U4.5 |
| `P2` | J6.5, U4.6 |
| `P3` | J6.6, U4.7 |
| `P4` | J6.7, U4.9 |
| `P5` | J6.8, U4.10 |
| `P6` | J6.9, U4.11 |
| `P7` | J6.10, U4.12 |
| `PUMP` | J7.3, U1.D26 |
| `QG` | Q1.1, R9.1 |
| `RAIN` | U1.D15, R7.1, R8.2, C4.1 |
| `RAIN_IN` | J11.1, R8.1 |
| `S0` | U1.D12, U5.11, R1.1 |
| `S1` | U1.D13, U5.10, R2.1 |
| `S2` | U1.D14, U5.9, R3.1 |
| `SCL` | U1.D22, U4.14, J9.3, R11.1 |
| `SDA` | U1.D21, U4.15, J9.4, R10.1 |
| `SD_CS` | U1.D5, J8.D8 |
| `SD_MISO` | U1.D19, J8.D6 |
| `SD_MOSI` | U1.D23, J8.D7 |
| `SD_SCK` | U1.D18, J8.D5 |
| `Y0` | U5.13, S1.3 |
| `Y1` | U5.14, S2.3 |
| `Y2` | U5.15, S3.3 |
| `Y3` | U5.12, S4.3 |
| `Y4` | U5.1, S5.3 |
| `Y5` | U5.5, S6.3 |
| `Y6` | U5.2, S7.3 |
| `Y7` | U5.4, S8.3 |

## Компоненты

| Ref | Значение | Посадочное место |
|---|---|---|
| J1 | 12V IN | Клеммник KF301/KF2EDG 5.08 2P |
| J3 | 12V VALVES | Клеммник KF301/KF2EDG 5.08 2P |
| J4 | 12V PUMP | Клеммник KF301/KF2EDG 5.08 2P |
| J6 | RELAY 8: +5 GND IN1..IN8 | Клеммник KF2EDG 5.08 10P |
| J7 | RELAY 1: +5 GND PUMP | Клеммник KF301/KF2EDG 5.08 3P |
| J5 | RELAY 2: +5 GND FILL DRAIN | Клеммник KF2EDG 5.08 4P |
| F1 | F1 5A | Держатель предохранителя 5×20 |
| Q1 | IRF4905 | TO-220 стоя, крайние выводы разведены на 5.08: P-MOSFET защиты от переполюсовки (G D S) |
| R9 | 10k | Резистор 0.25 Вт |
| D2 | P6KE18CA | Диод DO-201 (1N5822) |
| C1 | 1000u/16V | Электролит 1000 мкФ, шаг 5 |
| U2 | DC-DC 12-5V 2A | Модуль DC-DC в корпусе TO-220 (IN GND OUT) |
| C2 | 100u | Электролит 100 мкФ, шаг 2.5 |
| U3 | DC-DC 5-3.3V | Модуль DC-DC в корпусе TO-220 (IN GND OUT) |
| C3 | 100u | Электролит 100 мкФ, шаг 2.5 |
| F2 | F2 3A | Держатель предохранителя 5×20 |
| U1 | ESP32 DevKitC 38 | Гнездо ESP32 DevKitC 38pin (2× гребёнка 1×19) |
| U4 | PCF8574P | Панелька DIP-16 |
| U5 | 74HC4051 | Панелька DIP-16 |
| J8 | SD D1 mini | Гнездо шилда Micro SD D1 mini (2× гребёнка 1×8) |
| J9 | DS3231 | Гнездо модуля DS3231 1×6, модуль 38×22 мм уходит влево |
| SW1 | RESET CFG | Кнопка тактовая 6×6 |
| R4 | 10k | Резистор 0.25 Вт |
| R1 | 10k | Резистор 0.25 Вт |
| R2 | 10k | Резистор 0.25 Вт |
| R3 | 10k | Резистор 0.25 Вт |
| R5 | 10k | Резистор 0.25 Вт |
| R6 | 33k | Резистор 0.25 Вт |
| C5 | 100n | Керамический конденсатор, шаг 5.08 |
| C6 | 100n | Керамический конденсатор, шаг 5.08 |
| R10 | 4.7k | Резистор 0.25 Вт |
| R11 | 4.7k | Резистор 0.25 Вт |
| JP1 | 3V3 SENS 5V | Штыри 1×3 + джампер |
| J10 | FLOW | Клеммник KF301/KF2EDG 5.08 3P |
| J12 | LDR | Клеммник KF301/KF2EDG 5.08 2P |
| U6 | LIGHT LM393 | Гнездо модуля датчика света LM393 1×3 (VCC GND DO), модуль 32×14 мм уходит влево |
| JL1 | LDR | Штыри 1×2 к площадкам фоторезистора модуля |
| J11 | RAIN SW | Клеммник KF301/KF2EDG 5.08 2P |
| R7 | 10k | Резистор 0.25 Вт |
| R8 | 1k | Резистор 0.25 Вт |
| C4 | 100n | Керамический конденсатор, шаг 5.08 |
| S1 | SOIL 1 | Клеммник KF301/KF2EDG 5.08 3P |
| S2 | SOIL 2 | Клеммник KF301/KF2EDG 5.08 3P |
| S3 | SOIL 3 | Клеммник KF301/KF2EDG 5.08 3P |
| S4 | SOIL 4 | Клеммник KF301/KF2EDG 5.08 3P |
| S5 | SOIL 5 | Клеммник KF301/KF2EDG 5.08 3P |
| S6 | SOIL 6 | Клеммник KF301/KF2EDG 5.08 3P |
| S7 | SOIL 7 | Клеммник KF301/KF2EDG 5.08 3P |
| S8 | SOIL 8 | Клеммник KF301/KF2EDG 5.08 3P |
| H1 | M3 | Отверстие М3, зона под головку винта |
| H2 | M3 | Отверстие М3, зона под головку винта |
| H3 | M3 | Отверстие М3, зона под головку винта |
| H4 | M3 | Отверстие М3, зона под головку винта |

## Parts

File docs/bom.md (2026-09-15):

# 🛒 Список покупок для платы-носителя

Прямые ссылки — товары, выбранные при проектировании. Остальное — поисковые ссылки AliExpress:
выбирайте лот с нужными параметрами из колонки «Что проверить».

## Модули

| # | Что | Кол-во | Что проверить | Ссылка |
|---|---|---|---|---|
| 1 | ESP32 DevKitC 38 pin, Type-C, CP2102, ESP-32U | 1 | вариант «Esp-32U TypeC CP2102» | [товар](https://aliexpress.ru/item/1005012242722260.html?sku_id=12000057908902979) |
| 2 | Антенна 2,4 ГГц с кабелем IPEX (u.FL) → SMA | 1 | разъём IPEX / u.FL, для ESP-32U обязательна | [поиск](https://aliexpress.ru/wholesale?SearchText=2.4G+antenna+IPEX+SMA+cable) |
| 3 | Модуль часов DS3231 | 1 | выводы 32K SQW SCL SDA VCC GND, не больше 38×22 мм; угловые штыри заменить прямыми | [товар](https://aliexpress.ru/item/1005008726872995.html?sku_id=12000046413640438) |
| 4 | Батарейка CR2032 | 1 | для DS3231 | [поиск](https://aliexpress.ru/wholesale?SearchText=CR2032) |
| 5 | Micro SD шилд D1 mini | 1 | вариант «Mini TF Card Module» | [товар](https://aliexpress.ru/item/1005006906986536.html?sku_id=12000038679692909) |
| 6 | Карта microSD | 1 | 4–32 ГБ | [поиск](https://aliexpress.ru/wholesale?SearchText=microSD+16GB) |
| 7 | Реле H/L, 8 каналов, 5 В | 1 | вариант «8 Channel 5V» | [товар](https://aliexpress.ru/item/1005005512612348.html?sku_id=12000033367250070) |
| 8 | Реле H/L, 2 канала, 5 В | 1 | вариант «2 Channel 5V» | [товар](https://aliexpress.ru/item/1005005512612348.html?sku_id=12000033367250060) |
| 9 | Реле H/L, 1 канал, 5 В | 1 | вариант «1 Channel 5V» | [товар](https://aliexpress.ru/item/1005005512612348.html?sku_id=12000033367250061) |
| 10 | Датчик освещённости LM393 | 1 | выход DO; ставится в гнездо на плате; угловые штыри заменить прямыми | [товар](https://aliexpress.ru/item/1005008442854218.html?sku_id=12000045155529451) |
| 10а | Фоторезистор GL5528 | 1 | выносной, вместо выпаянного с модуля (или используйте родной) | [поиск](https://aliexpress.ru/wholesale?SearchText=GL5528+photoresistor) |
| 10б | Кабель Dupont 2P, колодки 2,54 мм | 1 | вариант **10CM**, лот 10 шт. | [товар](https://aliexpress.ru/item/1005004560106052.html?sku_id=12000048220702533) |
| 11 | Ёмкостный датчик влажности v2.0 | 8 | лот 5 шт. → 2 лота; микросхема TLC555 | [товар](https://aliexpress.ru/item/1005009040921501.html?sku_id=12000047682480026) |
| 12 | Датчик дождя Rain Seer, проводной | 1 | вариант «Wired Rain Sensor2»; сухой контакт, замыкается при дожде | [товар](https://aliexpress.ru/item/1005004442230539.html?sku_id=12000029194430427) |
| 13 | Расходомер YF-S201 | 1 | резьба под вашу магистраль | [поиск](https://aliexpress.ru/wholesale?SearchText=YF-S201) |
| 14 | Импульсный DC-DC 12→5 В K7805-2000R3 | 1 | вариант **K7805-2000R3** (выбран в ссылке); 2 А, IN GND OUT | [товар](https://aliexpress.ru/item/1005012171799231.html?sku_id=12000057678077288) |
| 15 | Импульсный DC-DC 5→3,3 В K7803-1000R3 | 1 | вариант **K7803-1000R3** (выбран в ссылке); 1 А, IN GND OUT | [товар](https://aliexpress.ru/item/1005012171799231.html?sku_id=12000057678077290) |
| 16 | Источник питания 12 В | 1 | не менее 5 А | [поиск](https://aliexpress.ru/wholesale?SearchText=12V+5A+power+supply) |

## Микросхемы

| # | Что | Кол-во | Что проверить | Ссылка |
|---|---|---|---|---|
| 17 | PCF8574P | 1 | вариант **5pcs**, DIP-16, без буквы A | [товар](https://aliexpress.ru/item/1005009014808124.html?sku_id=12000047583092003) |
| 18 | 74HC4051N | 1 | DIP-16, лот 10 шт. | [товар](https://aliexpress.ru/item/1_492703621.html?sku_id=5000002488096960) |

## Детали для пайки на плату

| # | Поз. | Что | Кол-во | Что проверить | Ссылка |
|---|---|---|---|---|---|
| 19 | U1 | гребёнка-мама 1×20 | 2 | вариант **20P**, лот 10 шт.; отрезать до 1×19 | [товар](https://aliexpress.ru/item/1005006533889843.html?sku_id=12000037557939271) |
| 20 | J8 | гребёнка-мама 1×8 | 2 | вариант **8P**, тот же лот | [товар](https://aliexpress.ru/item/1005006533889843.html?sku_id=12000037557939265) |
| 21 | J9 | гребёнка-мама 1×6 | 1 | вариант **6P**, тот же лот | [товар](https://aliexpress.ru/item/1005006533889843.html?sku_id=12000037557939263) |
| 21а | U6 | гребёнка-мама 1×3 | 1 | вариант **3P**, тот же лот | [товар](https://aliexpress.ru/item/1005006533889843.html?sku_id=12000037557939260) |
| 21б | JL1, JP1 | штыри 1×20, режутся | 1 | лот 10 шт.: JL1 (1×2), два штыря на модуль света, JP1 (1×3) | [товар](https://aliexpress.ru/item/4000386932711.html?sku_id=10000001581997635) |
| 22 | U4, U5 | панелька DIP-16 | 2 | лот 10 шт. | [товар](https://aliexpress.ru/item/4000004724401.html?sku_id=10000000013372779) |
| 23 | J1, J3, J4, J11, J12 | клеммник KF2EDG 2P | 5 | **Прямоугольный**, 10 пар, вариант **2P** | [товар](https://aliexpress.ru/item/1_438686192.html?sku_id=5000002212067168) |
| 24 | J7, J10, S1–S8 | клеммник KF2EDG 3P | 10 | Прямоугольный, 10 пар, вариант **3P** | [товар](https://aliexpress.ru/item/1_438686192.html?sku_id=5000002212067167) |
| 25 | J5 | клеммник KF2EDG 4P | 1 | Прямоугольный, 5 пар, вариант **4P** | [товар](https://aliexpress.ru/item/1_438686192.html?sku_id=5000002212067158) |
| 26 | J6 | клеммник KF2EDG 10P | 1 | Прямоугольный, 5 пар, вариант **10P** | [товар](https://aliexpress.ru/item/1_438686192.html?sku_id=5000002212067154) |
| 27 | F1, F2 | держатель предохранителя на плату | 2 | вариант «5x20mm», 2PCS; выводы через 22 мм | [товар](https://aliexpress.ru/item/1005003003740005.html?sku_id=12000023167893560) |
| 28 | F1, F2 | предохранители 5×20 | по 1 | модель **5X20MM**; два лота по 10 шт.: вариант **5A** для F1 и **3A** для F2 | [товар](https://aliexpress.ru/item/1005013054362366.html?sku_id=12000060114427576) |
| 29 | Q1 | P-MOSFET IRF4905 | 1 | вариант **IRF4905** (выбран в ссылке), лот 10 шт.; корпус TO-220 | [товар](https://aliexpress.ru/item/1005009078862102.html?sku_id=12000047836545481) |
| 29а | D2 | TVS-диод P6KE18CA | 1 | вариант **P6KE18CA** (выбран в ссылке), лот 50 шт.; двунаправленный, буквы CA | [товар](https://aliexpress.ru/item/1005009012488338.html?sku_id=12000047575516033) |
| 30 | C1 | конденсатор 1000 мкФ 16 В | 1 | лот 10 шт., корпус ≈10×15 мм, шаг выводов 5 мм | [товар](https://aliexpress.ru/item/1005002697208131.html?sku_id=12000037070541348) |
| 31 | C2, C3 | конденсатор 100 мкФ 16 В | 2 | вариант **16V100UF 20PCS** (выбран в ссылке); шаг выводов 2,5 мм | [товар](https://aliexpress.ru/item/1005002075527957.html?sku_id=12000018654903094) |
| 32 | R1–R5, R7, R9 | резистор 10 кОм 0,25 Вт | 7 | вариант **10K** (лот 150 шт.) | [товар](https://aliexpress.ru/item/1005011888190705.html?sku_id=12000056892789364) |
| 33 | R6 | резистор 33 кОм 0,25 Вт | 1 | вариант **33K**, тот же лот | [товар](https://aliexpress.ru/item/1005011888190705.html?sku_id=12000056892789364) |
| 33в | R10, R11 | резистор 4,7 кОм 0,25 Вт | 2 | вариант **4.7K**, тот же лот | [товар](https://aliexpress.ru/item/1005011888190705.html?sku_id=12000056892789364) |
| 33а | R8 | резистор 1 кОм 0,25 Вт | 1 | вариант **1K**, тот же лот | [товар](https://aliexpress.ru/item/1005011888190705.html?sku_id=12000056892789364) |
| 33б | C4, C5, C6 | конденсатор 100 нФ керамический | 3 | вариант **100NF** (выбран в ссылке), лот 100 шт.; шаг выводов 5 мм, при 2,5 мм выводы разогнуть | [товар](https://aliexpress.ru/item/1005011778544822.html?sku_id=12000056520661652) |
| 34 | SW1 | кнопка тактовая 6×6 | 1 | 6×6×6 мм, 4 вывода, лот 50 шт. | [товар](https://aliexpress.ru/item/32815841388.html?sku_id=64712982838) |
| 35 | JP1 | джампер 2,54 мм | 1 | штыри — из строки 21б | [товар](https://aliexpress.ru/item/1005008466863615.html?sku_id=12000045263870726) |

## Монтаж

| # | Что | Кол-во | Что проверить | Ссылка |
|---|---|---|---|---|
| 36 | Стойки М3 пластиковые + винты | ~16 | высота 10 мм | [поиск](https://aliexpress.ru/wholesale?SearchText=M3+nylon+standoff+kit) |
| 37 | Наконечники НШВИ + клещи | набор | клещи HSC8 6-4 | [поиск](https://aliexpress.ru/wholesale?SearchText=HSC8+6-4+ferrule+crimper+kit) |
| 38 | Корпус ABS IP65 | 1 | 250×200×80 мм | [поиск](https://aliexpress.ru/wholesale?SearchText=ABS+junction+box+IP65+250x200x80) |
| 39 | Гермовводы PG9 | 5 | под диаметр ваших кабелей | [поиск](https://aliexpress.ru/wholesale?SearchText=PG9+cable+gland) |

## Сама плата

| # | Что | Кол-во | Параметры | Где |
|---|---|---|---|---|
| 40 | Печатная плата 150×110 мм | по минимальному заказу | 2 слоя, 1,6 мм, архив `hardware/DripCarrier-gerbers.zip` (собирается командой `bash hardware/kicad-docker.sh`, в git не хранится) | [Service Devices](https://service-devices.com/pechatnie-plati-zakaz/) |

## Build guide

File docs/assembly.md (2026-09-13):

# 🔧 Пошаговая сборка платы-носителя

Детали паяются от самых низких к самым высоким. Тогда плату можно положить деталями вниз на стол,
и прижатая к столу деталь не выпадет, пока паяете её выводы снизу.

Все детали ставятся **на верхнюю сторону** (где подписи), паяются **с нижней**.
Модули и микросхемы вставляются только в самом конце, после проверки питания.

**Инструмент:** паяльник 40–60 Вт с жалом «конус» или «микроволна», припой ПОС-61 0,8–1 мм с флюсом,
кусачки, пинцет, мультиметр, изопропиловый спирт и щётка для отмывки флюса.

---

## Шаг 1. Резисторы и TVS-диод

Шаг 1

| Поз. | Деталь | Как ставить |
|---|---|---|
| R1, R2, R3, R4, R5, R7, R9 | 10 кОм (коричневый-чёрный-оранжевый) | полярности нет |
| R6 | 33 кОм (оранжевый-оранжевый-оранжевый) | полярности нет |
| R8 | 1 кОм (коричневый-чёрный-красный) | полярности нет |
| R10, R11 | 4,7 кОм (жёлтый-фиолетовый-красный) | полярности нет |
| D2 | TVS P6KE18CA, правый край у F2 | двунаправленный, полярности нет |

1. Отформуйте выводы по расстоянию между отверстиями, вставьте деталь до упора в плату.
2. Слегка разогните выводы снизу, чтобы деталь не выпала.
3. Переверните плату, пропаяйте, откусите выводы на высоте 1 мм.

> ⚠️ Сверьте номиналы резисторов мультиметром, если сомневаетесь в цветовой маркировке:
> четыре разных номинала легко перепутать. TVS должен быть с буквами **CA** в конце: однонаправленный
> P6KE18A будет замыкать шину 12 В.

---

## Шаг 2. Керамические конденсаторы, кнопка и штыри

Шаг 2

| Поз. | Деталь | Как ставить |
|---|---|---|
| C4, C5, C6 | керамические 100 нФ (маркировка 104) | полярности нет |
| SW1 | кнопка 6×6 | вставляется только в одном положении, дожать до щелчка |
| JP1 | штыри 1×3 | короткой частью в плату, **без джампера** |
| JL1 | штыри 1×2 | короткой частью в плату |

Штыри держите пинцетом или прижмите к столу, пропаяйте один вывод, проверьте, что стоят ровно,
потом пропаяйте остальные.

---

## Шаг 3. Панельки DIP-16

Шаг 3

| Поз. | Деталь | Как ставить |
|---|---|---|
| U4 | панелька DIP-16 | **вырез-ключ вверх**, к квадратной площадке вывода 1 |
| U5 | панелька DIP-16 | вырез-ключ вверх, к квадратной площадке |

1. Вставьте панельку, пропаяйте два угловых вывода по диагонали.
2. Проверьте, что панелька лежит плотно, без перекоса. Если нет — прогрейте угол и дожмите.
3. Пропаяйте остальные 14 выводов.

Микросхемы в панельки **пока не вставлять**.

---

## Шаг 4. Гнёзда модулей

Шаг 4

| Поз. | Деталь | Для чего |
|---|---|---|
| U1 | 2 гребёнки-мамы 1×19 | ESP32 |
| J8 | 2 гребёнки-мамы 1×8 | SD-шилд |
| J9 | гребёнка-мама 1×6 | DS3231 |
| U6 | гребёнка-мама 1×3 | модуль датчика света |

**Главное — гнёзда должны стоять параллельно друг другу**, иначе модуль не войдёт.
Самый надёжный способ:

1. Вставьте в гнёзда сам модуль, затем вставьте гнёзда с модулем в плату.
2. Переверните плату вместе с модулем, пропаяйте по одному крайнему выводу каждой гребёнки.
3. Проверьте ровность, пропаяйте все остальные выводы.
4. Выньте модуль.

> Перед этим шагом подготовьте DS3231 и модуль света: **угловые штыри замените прямыми**, торчащими вниз
> со стороны без деталей. С модуля света выпаяйте фоторезистор и впаяйте на его место два штырька.

---

## Шаг 5. Электролиты, преобразователи и MOSFET

Шаг 5

| Поз. | Деталь | Как ставить |
|---|---|---|
| C1 | 1000 мкФ 16 В | **длинная ножка (+) — к метке +**, светлая полоса на корпусе — от метки |
| C2, C3 | 100 мкФ 16 В | длинная ножка к метке + |
| U2 | DC-DC 12→5 В, **импульсный**, 2 А | вывод IN к метке IN, вывод OUT к метке OUT |
| U3 | DC-DC 5→3,3 В, **импульсный** | вывод IN к метке IN, вывод OUT к метке OUT |
| Q1 | P-MOSFET IRF4905 | крайние выводы развести на 5,08 мм; **металлическая спинка — к F1**, вывод G к метке G, S к метке S |

> ⚠️ Конденсатор, впаянный наоборот, вздувается или лопается при первом включении.
> ⚠️ Q1 наоборот — плата не включится, но не сгорит: канал и защитный диод MOSFET окажутся заперты.
> ⚠️ Проверьте, что U2 и U3 — импульсные модули (K7805-2000, K7803-1000), а не линейные L7805:
> линейный на этом месте перегреется. Порядок выводов IN · GND · OUT сверьте с надписью на модуле.

---

## Шаг 6. Держатели предохранителей

Шаг 6

| Поз. | Деталь | Как ставить |
|---|---|---|
| F1 | держатель 5×20 | полярности нет |
| F2 | держатель 5×20 | полярности нет |

Держатели массивные и долго прогреваются: держите паяльник на выводе 3–4 секунды, пока припой
не растечётся по всей площадке. Вставки предохранителей **пока не ставить**.

---

## Шаг 7. Клеммники

Шаг 7

| Поз. | Клеммник | Где |
|---|---|---|
| J1, J3, J4 | 2P | верхний край: вход 12 В, 12 В клапаны, 12 В насос |
| J6 | 10P (или 5 шт. 2P, сдвинутые вплотную) | верхний край: реле 8 каналов |
| J7 | 3P | верхний край: реле насоса |
| J5 | 4P | верхний край: реле налива и дренажа |
| J10 | 3P | правый край: расходомер |
| J12 | 2P | правый край: выносной фоторезистор |
| J11 | 2P | правый край: датчик дождя |
| S1…S8 | 3P | нижний край: датчики влажности |

**Отверстия для проводов — всегда наружу, к краю платы.** Винты — сверху.

1. Если собираете длинную колодку из нескольких клеммников, сначала сцепите их пазами.
2. Прижмите клеммник к плате, пропаяйте крайний вывод, проверьте, что не перекосился.
3. Пропаяйте остальные выводы, не жалея припоя: через эти выводы идёт ток клапанов.

---

## Шаг 8. Проверка питания без модулей

На этом шаге модули и микросхемы **ещё не вставлены**.

1. **Прозвонка до включения.** Мультиметром в режиме прозвонки проверьте, что нет короткого замыкания:
   * между контактами клеммника J1 (12 В и GND);
   * между +5 В и GND на клеммнике J6, контакты 1 и 2;
   * между 3,3 В и GND: вывод 16 и вывод 8 панельки U4.
2. **Вставьте предохранитель 5 А в F1** и **3 А в F2**.
3. **Подайте 12 В на J1** от блока питания. Проверьте напряжения:

| Где мерить | Должно быть |
|---|---|
| J3, между контактами | 11,5–12,5 В |
| J6, контакты 1 и 2 | 4,9–5,1 В |
| панелька U4, вывод 16 относительно вывода 8 | 3,2–3,4 В |
| JP1, крайний штырь у подписи 5V относительно GND | 4,9–5,1 В |

4. Подержите 5 минут. Потрогайте U2, U3, Q1 — они должны быть едва тёплыми.
5. **Отключите питание.**

Если напряжения нет или что-то греется — ищите ошибку до установки модулей: чаще всего это
перевёрнутый MOSFET, конденсатор или замыкание припоем между соседними выводами.

---

## Шаг 9. Микросхемы и джампер

Шаг 9

| Поз. | Деталь | Как ставить |
|---|---|---|
| U4 | PCF8574P | **ключ (выемка или точка) — к вырезу панельки**, вверх |
| U5 | 74HC4051 | ключ к вырезу панельки, вверх |
| JP1 | джампер | на **3V3**, если на датчиках влажности TLC555; на **5V**, если NE555 |

Выводы новой микросхемы разведены чуть шире панельки: слегка подожмите их о стол, по одному ряду
за раз. Вставляйте ровно, без усилия, следите, чтобы ни одна ножка не загнулась под корпус.

---

## Шаг 10. Модули

Шаг 10

| Поз. | Модуль | Как ставить |
|---|---|---|
| U1 | ESP32 DevKitC 38 | **разъём USB — вниз**, к подписи USB; антенна вверх. Подпись 3V3 на модуле — у подписи 3V3 на плате |
| J8 | SD-шилд D1 mini | подписи выводов модуля совпадают с подписями на плате: 3V3, D5…D8, G |
| J9 | DS3231 | модуль лежит **влево** от гнезда, над пунктирным контуром; батарейку CR2032 вставить |
| U6 | модуль датчика света | модуль лежит влево от гнезда; кабель на 2 провода — со штырей модуля на JL1 |

Подключите антенну к разъёму IPEX на ESP32: защёлкните разъём прямо сверху до щелчка.

**Первое включение с модулями:**

1. Подайте 12 В на J1. На ESP32 должен загореться светодиод питания.
2. Подключите ESP32 по USB к компьютеру и прошейте.
3. В логе прошивки должны появиться часы, SD-карта и расширитель PCF8574.

---

## Шаг 11. Реле и внешние провода

Провода к клеммникам — только с обжатыми наконечниками НШВИ.

1. **Реле 8 каналов** — к J6: +5 В на DC+, GND на DC−, IN1…IN8 по порядку. Перемычки на модуле — в **L**.
2. **Реле 1 канал** — к J7, перемычка в **H**. **Реле 2 канала** — к J5, перемычки в **H**.
3. Щёлкните каналами из меню бота: каждое реле должно срабатывать.
4. Подключите клапаны, насос, датчики, выносной фоторезистор, датчик дождя.
5. Откалибруйте датчики влажности.

Подробно про реле, перемычки H/L и датчики — в [описании платы](hardware-carrier-board.md).

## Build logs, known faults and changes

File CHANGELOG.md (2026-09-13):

# [1.10.0](https://github.com/akprof2000/DripIrrigation/compare/v1.9.3...v1.10.0) (2026-09-13)

> 🔍 Ревизия прошивки: 17 находок закрыты. Плата-носитель (`hardware/`) доведена
> до заказа. Прошивка 1 270 673 байт: 97 % старого раздела, 64 % `min_spiffs`.

### 🐞 Исправления (Bug Fixes)

* **Ошибка Telegram API больше не считается потерей WiFi.** Раньше любой `ok=false`
  (заблокировавший бота пользователь, плохой HTML) запускал до 54 с блокирующего
  переподключения в `loop()`, и дренаж с наливом переживали свои таймауты.
  Переподключение — только при реальном обрыве WiFi, ожидание ограничено 3 с
* **Название культуры режется по границе UTF-8** (`utf8Truncate`): длинное
  кириллическое имя ломало все сообщения с этим названием
* **Портал настройки** каждый раз строит страницу заново: повторный запуск в одной
  загрузке показывал старое кодовое слово, и владельца нельзя было зарегистрировать
* **Пароль WiFi до 63 символов** (было 31), SSID до 32. Новые поля в EEPROM с адреса
  512, старые значения переносятся автоматически, остальная раскладка не тронута
* **Регистрация владельца** требует настоящего кодового слова: пустое сообщение
  при незаписанном EEPROM больше не даёт роль
* **Откат часов назад** (первая NTP-синхронизация при неверном RTC) не замораживает
  полив: сравнение минуты `!=` вместо `<`, беззнаковая разность в проливе защищена
* **Нагрузки гасятся до перезагрузки и в аварии** (`loadsOff()`): PCF8574 — отдельная
  защёлка, открытые клапаны переживали `ESP.restart()`. Сброшен `pumpStart`, иначе
  закрытие клапана снова включало насос
* **Выходы реле выставляются первой строкой `setup()`**, а не после портала и WiFi
* **Входы с подтяжкой**: кнопка `INPUT_PULLDOWN` (плавающий вход стирал настройки),
  дождь `INPUT_PULLUP`, свет `INPUT_PULLDOWN`
* **SD-карта**: одно уведомление о потере и одно о восстановлении вместо 1440 в сутки;
  проверка открытия файла
* **Команды с индексом** (`/BordersSet_abc`) отвергаются, а не попадают в канал 0;
  диалоги «граница» и «режим» переспрашивают при непонятном вводе

### ⚡ Производительность

* `/status` и `/WaterFlow` собираются через `reserve()` + `+=`, без 60 реаллокаций
* Опрос датчика влажности: 20 мс на канал вместо 50

### 🧹 Чистка

* Удалены `flowLastSessionPulses`, `CHECK_LIGHT`/`CHECK_RAIN`; `dropCDCard`/`connectCDCard`
  теперь используются

### 🧩 Плата-носитель (hardware/)

* Кнопка сброса под логику прошивки (подтяжка к земле), MOSFET IRF4905 вместо диода,
  TVS на 12 В, развязка, подтяжки I2C, дорожки 12 В — 2 мм. DRC KiCad 10: 0 ошибок
* 3D-просмотрщик работает без интернета (three.js встроен)

# [1.9.3](https://github.com/akprof2000/DripIrrigation/compare/v1.9.2...v1.9.3) (2026-08-07)

> 🗜️ Освобождение флеша: логи отключены полностью. 99 % → 98 % раздела.

### 🔧 Сборка (Build)

* **`LOG_LEVEL` = `LOG_LEVEL_NONE`** (было `LOG_LEVEL_ERROR`): вырезаны последние
  9 вызовов `LOG_E` вместе со строками форматов, реализация `logPrintf` (весь
  `log.cpp` под `#if LOG_LEVEL > LOG_LEVEL_NONE`) и `Serial.begin` в `setup()` —
  значит линкер выбрасывает и UART-стек. **1 303 685 → 1 292 149 байт, экономия
  11.3 КБ**, свободно 18.5 КБ из 1.31 МБ
* ⚠️ Диагностики по Serial теперь нет вообще. Отказы железа по-прежнему видны в
  чате — реестр неисправностей (`faults.h`) и отчёты бота от логгера не зависят.
  Для отладки на стенде вернуть `LOG_LEVEL_DEBUG` в `log.h` и пересобрать
* 📌 Радикальное решение по месту — схема разделов `min_spiffs` (1.96 МБ под
  приложение с сохранением OTA, те же байты дадут ~65 %). Она **не применяется
  через OTA**: смена таблицы разделов требует прошивки по кабелю

# [1.9.2](https://github.com/akprof2000/DripIrrigation/compare/v1.9.1...v1.9.2) (2026-08-07)

> 💧 Датчик потока не показывал расход при капельном поливе: пороги замера были
> рассчитаны на «шланговые» скорости. Добавлена диагностика самого датчика.

### 🐞 Исправления (Bug Fixes)

* **замер потока на капельных расходах:** окно замера длилось 30 с при пороге
  значимости `FM_MIN_PULSES = 40` импульсов. При 450 имп/л это означало отсечку
  на **0.18 л/мин суммарно по всем каналам** — то есть любой настоящий капельный
  полив (0.05–0.1 л/мин на канал) уходил в ветку «почти нет потока — пустой
  бак/сухой ход», и контроль засора фильтра не работал вовсе. Окно увеличено до
  120 с, порог снижен до 10 импульсов — отсечка стала 0.011 л/мин, ниже порога
  страгивания любой крыльчатки, так что в «нет потока» попадает только реальное
  отсутствие воды
* **ложная стабилизация потока:** подынтервал ожидания 20 с при капельном расходе
  давал ~7 импульсов, то есть шаг квантования ~14 % — больше порога
  `FM_SETTLE_STABLE_PCT` (10 %), и детектор «поток перестал падать» срабатывал на
  шуме округления. Подынтервал увеличен до 60 с (~22 импульса, шаг ~4.5 %)

### ✨ Новые возможности (Features)

* **🩺 диагностика датчика потока в `/WaterFlow`:** время с последнего импульса,
  мгновенная скорость (по интервалу между двумя последними импульсами, без
  ожидания 2-минутного окна) в л/мин и мл/с, калибровочный коэффициент и число
  открытых клапанов. Явное сообщение «импульсов не было ни разу», если крыльчатка
  не вращалась с момента включения — по нулевым литрам это было неотличимо от
  закрытых клапанов
* ⚠️ Если диагностика показывает, что импульсов нет при заведомо текущей воде —
  дело в датчике, а не в прошивке: YF-S201 (450 имп/л) рассчитан на 1–30 л/мин и
  на капельных расходах физически не страгивается. Нужен YF-S402 (980 имп/л, от
  0.3 л/мин) или лепестковый датчик; коэффициент правится в `FLOW_PULSES_PER_LITER`
  (перенесён в `objects.h`)

# [1.9.1](https://github.com/akprof2000/DripIrrigation/compare/v1.9.0...v1.9.1) (2026-08-01)

> 🔁 Исправлено зацикливание OTA: устройство обновлялось по кругу.
> Сборка: exit 0, флеш 97 %.

### 🐞 Исправления (Bug Fixes)

* **бесконечное обновление:** после прошивки устройство получало тот же файл
  снова и уходило в новый цикл OTA. Две причины:
  1. Telegram удаляет апдейт из очереди только когда бот запросит следующий
     пакет с бо́льшим `offset`. Наш `.gz`-OTA делал `ESP.restart()` мгновенно —
     подтверждения не было, и сервер отдавал сообщение с прошивкой заново
     (штатный `.bin`-OTA библиотеки этого избегает: он ждёт следующего
     `getUpdates` и только потом перезагружается);
  2. `skipUpdates()` при старте очередь НЕ чистит — по API Telegram
     отрицательный offset возвращает ПОСЛЕДНИЙ апдейт, то есть ровно то
     сообщение с файлом, которое и вызвало перезагрузку
* **позиция очереди переживает перезагрузку:** следующий ожидаемый `update_id`
  сохраняется в EEPROM (адрес 180) и восстанавливается в `botInit` — защищает
  даже при пропадании питания посреди обновления
* **подтверждение серверу:** перед рестартом после `.gz`-OTA вызывается
  `tickManual()`; позиция фиксируется заранее — до начала прошивки как для
  `.bin`, так и для `.gz`, и перед перезагрузкой из меню

# [1.9.0](https://github.com/akprof2000/DripIrrigation/compare/v1.8.0...v1.9.0) (2026-08-01)

> 🩺 Аппаратные ошибки больше не вешают систему молча: неисправность приходит
> в чат, а бот переходит в аварийный режим. Сборка: exit 0, флеш 97 %.

### 🐞 Исправления (Bug Fixes)

* **зависание при неисправном железе:** отсутствие RTC или SD-карты вешало
  прошивку в бесконечном `while` ещё до старта `loop()` — бот не поднимался,
  сообщений не было, и причину можно было узнать только подключившись кабелем.
  Теперь инициализация RTC, SD-карты и платы клапанов неблокирующая: несколько
  попыток, и загрузка продолжается в любом случае

### ✨ Новые возможности (Features)

* **реестр неисправностей** (`faults.h/.cpp`): каждый узел (RTC, SD, PCF8574)
  отмечается исправным или сбойным с короткой причиной
* **отчёт в чат:** при старте бот присылает список неисправностей с пояснением
  последствий. Если в момент старта связи не было, отчёт уходит позже — как
  только связь появится
* **аварийный режим бота:** пока железо неисправно, обычный интерфейс скрыт —
  на любую команду показывается отчёт и единственная кнопка «Перезагрузка»
* **безопасное гашение нагрузок:** при аварии насос, дренаж и залив бака
  выключаются напрямую по пинам, не полагаясь на возможно мёртвый PCF8574;
  клапаны закрываются, только если плата расширителя отвечает
* **полив останавливается** — работать с неисправным оборудованием опасно, зато
  бот и watchdog продолжают жить, и систему можно поднять кнопкой из чата

# [1.8.0](https://github.com/akprof2000/DripIrrigation/compare/v1.7.2...v1.8.0) (2026-08-01)

> 🔐 Токен бота переехал из прошивки в EEPROM — теперь готовые бинарники из
> GitHub рабочие и не содержат секретов. Сборка: exit 0, флеш 96 %.

### 🐞 Исправления (Bug Fixes)

* **бинарники из релизов не работали:** CI собирал прошивку с заглушкой
  `PUT-YOUR-BOT-TOKEN-HERE` вместо токена (токен компилировался внутрь образа).
  После такой прошивки устройство не выходило на связь, OTA становился
  недоступен — восстановление только по проводу

### ✨ Новые возможности (Features)

* **токен бота в EEPROM:** вводится на странице настройки WiFi и хранится в
  EEPROM (адрес 110). Порядок разрешения: EEPROM → `secrets.h` → портал, поэтому
  сборки со своим `secrets.h` продолжают работать без изменений
* **портал только для токена:** если токена нет ни в EEPROM, ни в прошивке,
  поднимается портал ТОЛЬКО для его ввода — настройки WiFi, список пользователей,
  калибровки и параметры полива сохраняются, после ввода система продолжает
  загрузку с того же места, без сброса
* **поле «Токен» можно оставить пустым** при перенастройке WiFi — сохранённый
  токен не изменится
* **без токена полив работает автономно:** бот не запускается, но автоматика
  продолжает поливать по расписанию и влажности

# [1.7.2](https://github.com/akprof2000/DripIrrigation/compare/v1.7.1...v1.7.2) (2026-07-31)

> 📎 Мелочи удобства вокруг OTA. Сборка: exit 0, флеш 96 %.

### ✨ Улучшения (Improvements)

* **имена файлов-копий:** OTA принимает файлы с суффиксом, который Windows
  добавляет при повторном скачивании — `DripIrrigation.ino.bin (2).gz`,
  `DripIrrigation.ino (2).bin`. Вместо точного сравнения имени проверяются
  префикс (защита от прошивки случайным документом) и расширение, регистр
  игнорируется
* **понятный отказ:** если владелец прислал файл с неподходящим именем, бот
  писал «Только владелец системы может отправлять обновления» — теперь отвечает
  «Это не похоже на прошивку: <имя>» и напоминает ожидаемые имена
* **повторные попытки скачивания `.gz`:** до 3 попыток с паузой. Скачивание —
  самое хрупкое место OTA: на TLS-хендшейк нужен крупный непрерывный кусок
  памяти, а после долгой работы куча фрагментирована (у штатного OTA это видно
  как «OTA Fetch Error»). Сообщение об ошибке теперь подсказывает перезагрузить
  систему и повторить

# [1.7.1](https://github.com/akprof2000/DripIrrigation/compare/v1.7.0...v1.7.1) (2026-07-31)

> 🐞 Исправление `.gz`-OTA из 1.7.0: на боевом устройстве обновление не
> применялось. Сборка: exit 0, флеш 96 %.

### 🐞 Исправления (Bug Fixes)

* **`.gz`-OTA не применялся:** распаковка шла напрямую из сетевого потока, а
  `StreamReader::readBytes()` уменьшает счётчик остатка ДО фактического чтения —
  если сокет отдавал меньше байт (пауза мобильного канала), поток
  рассинхронизировался и распаковка обрывалась. Теперь обновление в два этапа:
  архив скачивается на SD штатным буферизованным `writeTo()` библиотеки, и уже
  оттуда распаковывается — чтение с карты не зависит от связи
* **диагностика в чат:** при неудаче бот присылает причину (код распаковки,
  ошибка `Update`, сколько байт распаковано) — в рабочей прошивке логи выключены,
  иначе причину не узнать
* **временный файл** `/update.gz` удаляется после обновления и при любой ошибке;
  перед новой попыткой остаток от предыдущей затирается

# [1.7.0](https://github.com/akprof2000/DripIrrigation/compare/v1.6.0...v1.7.0) (2026-07-03)

> 🗜️ OTA теперь принимает сжатый `DripIrrigation.ino.bin.gz` — распаковка gzip
> идёт прямо на ESP32, файл для отправки в ~1.6 раза меньше. Сборка: exit 0,
> флеш 96 %.

### ✨ Новые возможности (Features)

* **OTA из сжатого .gz:** можно слать боту `DripIrrigation.ino.bin.gz` (≈0.8 МБ
  вместо 1.3 МБ) — устройство скачивает архив и распаковывает gzip потоково во
  flash. Раньше `.gz` формально принимался, но прошить его было нельзя: FastBot2
  на ESP32 пишет байты во flash как есть, без распаковки (в отличие от ESP8266)
* **потоковый распаковщик:** добавлена библиотека uzlib (vendored, zlib-лицензия);
  gzip разбирается на лету, LZ-окно 32 КБ, выход пишется в Update кусками —
  вся прошивка в память не грузится
* **безопасность:** распаковка идёт в НЕАКТИВНЫЙ OTA-раздел, загрузка
  переключается только при валидном образе (Update.end) + проверка CRC32
  gzip-трейлера. Сбой распаковки → отказ OTA, а не кирпич. Тяжёлое скачивание
  вынесено из колбэка bot.tick() в loop(), watchdog сбрасывается по ходу

> ⚠️ Путь `.gz`-OTA новый — перед боевым применением проверьте на стенде.
> Обычный `.bin` работает как прежде.

# [1.6.0](https://github.com/akprof2000/DripIrrigation/compare/v1.5.0...v1.6.0) (2026-07-03)

> 🏷️ Версия прошивки теперь видна в чате — при старте и в `/status`. Так сразу
> понятно, применилась ли OTA-прошивка. Сборка: arduino-cli (esp32 3.3.10), exit 0.

### ✨ Новые возможности (Features)

* **версия прошивки в чате:** при запуске система пишет «🚀 Система запущена!
  Прошивка vX.Y.Z», а также показывает версию в шапке `/status` — удобно
  проверить, что OTA-обновление действительно применилось
* **единая точка версии:** номер вынесен в `version.h` (`FW_VERSION`), совпадает
  с git-тегом релиза

# [1.5.0](https://github.com/akprof2000/DripIrrigation/compare/v1.4.0...v1.5.0) (2026-07-03)

> 🌾 Полевой релиз: исправлены проблемы, всплывшие при реальной эксплуатации
> (насос не выключался, ложные тревоги о засоре, залипшая кнопка «ДАЛЕЕ»),
> добавлена авто-калибровка границ датчиков. Проект переехал на GitHub.
> Сборка: arduino-cli (esp32 3.3.10), exit 0, флеш 97 %.

### ✨ Новые возможности (Features)

* **авто-калибровка границ датчиков влажности:** если показание вышло за границу,
  заданную при калибровке, граница отодвигается до этого значения с запасом в
  дельту калибровки. Границы только расширяются. Разовые выбросы АЦП отсекаются
  подтверждением: сдвиг только если превышение держится 3 минутных замера подряд
  (внутри окна берётся самое мягкое значение). Во время диалогов калибровки и
  поиска датчика функция отключается — иначе она «выучила» бы калибровочные
  экстремумы как рабочий диапазон
* **настройка «Авто-калибровка без задержки»:** отключает подтверждение — граница
  двигается по первому же замеру за ней (по умолчанию выключено)
* **состояние насоса в `/status`:** видно, работает ли насос повышения давления
  и почему (пусковой режим / порог открытых клапанов / пролив дренажа), плюс
  текущая настройка порога
* **название культуры в калибровке:** во всех диалогах и меню калибровки датчик
  подписан как «N (Название)» — понятно, какой именно настраивается

### 🐞 Исправления (Bug Fixes)

* **насос не выключался:** защита по таймауту считалась по unix-времени и не
  срабатывала, если RTC/NTP не синхронизированы. Переведена на `millis()` —
  монотонные часы, не зависящие от синхронизации. Как следствие чинилось и
  отображение потока: гейт замера ждал обнуления `pumpStart`, которое не наступало
* **пусковой режим насоса прерывался проливом дренажа:** завершение пролива
  выключало насос на 12-й секунде, хотя после открытия клапана он обязан работать
  минимум 30 с. Особенно заметно было после перезагрузки
* **ложная тревога о засоре фильтра:** при заполнении труб поток кратковременно
  завышен и потом плавно падает — это принималось за засор. Добавлено адаптивное
  ожидание стабилизации (минимум 10 мин, потолок 15 мин) и защита эталона от
  разовых выбросов (подтверждение минимумом за 5 мин)
* **расчёт засора при частично открытых клапанах:** эталон переведён на скорость
  «на клапан» (`cleanFlowPerValve`), пролив дренажа вынесен в отдельный эталон
* **кнопка «➡️ ДАЛЕЕ» не реагировала:** эмодзи U+27A1 несёт вариационный селектор
  U+FE0F, который теряется при round-trip через Telegram, и точное сравнение
  строки не срабатывало. Все reply-кнопки переведены на сравнение по текстовой
  части без эмодзи (`btnIs`)
* **клавиатура оставалась на экране** после завершения калибровки — теперь убирается
* **рассинхрон при сбросе настроек:** сброс обнулял границы только в конфиге, а
  объект датчиков держал в RAM старые — проценты считались по ним до перезагрузки
* **переполнение буфера** при переименовании датчика (`strcpy` произвольного текста
  в `char[90]`), **выход за границы массивов** по индексу канала из команды и при
  разборе повреждённого CSV, деление на 0 в графиках
* **меню «Настройка» не открывалось** после текстовых ответов: `editText` работает
  только в контексте callback-кнопки. Все меню переведены на единый `showMenu()`
* **дельта калибровки:** дефолт структуры (30) не совпадал со «Сбросом настроек»
  в боте (15) — приведено к 15

### ⚡ Улучшения (Improvements)

* **таймаут потери связи с Telegram:** 150 → 180 с по умолчанию — меньше ложных
  уведомлений о кратковременных обрывах канала
* **датчик влажности:** установление 50 мс + медиана из 9 замеров вместо одного —
  устойчивость к помехам
* **миграция настроек без сброса:** FileData переведён в режим `addWithoutWipe()` —
  при добавлении полей в конец `Config` старые настройки переживают обновление
  прошивки (без бампа версии конфига, который запускал бы портал WiFi и очистку
  пользователей)
* **README:** полная пользовательская инструкция — роли, типовые сценарии, распиновка,
  формат CSV, расшифровка статуса; схемы перерисованы в SVG (подключение, алгоритм,
  гистерезис, тайминг насоса, контроль фильтра)
* **проект на GitHub:** github.com/akprof2000/DripIrrigation, история очищена от токенов

# [1.4.0](https://akprof2000.visualstudio.com/compare/v1.3.0...v1.4.0) (2026-06-27)

> 🏛️ Проход по «чистой архитектуре»: разделение ответственностей, выделение модулей,
> устранение магических чисел и секретов в исходниках. Поведение не менялось —
> только структура. Сборка проверена через arduino-cli (esp32 3.3.10), exit 0.

### ♻️ Архитектура (Refactoring)

* **полив — ядро/оболочка:** доменная логика клапанов вынесена в `irrigation.h/.cpp`
  (чистая `decideValve()` без I/O, тестируется на ПК); `checkValve()` стал тонкой
  оболочкой «решение → действие → уведомление»
* **пользователи — отдельный модуль:** модель и хранение в EEPROM вынесены в
  `users.h/.cpp`; презентация (стартовые меню) осталась в `telegram.cpp`
* **распил `telegram.cpp`:** выделены `botutil` (строковые утилиты),
  `bot_transport` (отправка/рассылки), `reports` (графики/удаление файлов);
  в `telegram.cpp` осталась маршрутизация команд, FSM и меню
* **коды диалогов:** «магические» числа состояний FSM заменены на именованные
  константы `namespace Dlg` (диапазоны параметризованы числом каналов)
* **заголовки:** `objects.h` расщеплён — пины в `pins.h`, тайминги в `timing.h`
* **секреты:** токен бота вынесен в `secrets.h` (в `.gitignore`) + `secrets.example.h`
* **версионирование настроек:** в `Config` добавлены `magic`+`version`; при несовпадении
  настройки сбрасываются в дефолты, а не читаются как «мусор»
* **чистка:** удалён мёртвый модуль `logger`

> ⚠️ При обновлении: добавление полей в `Config` вызывает однократный сброс настроек
> на устройстве (как и в 1.3.0) — пройди калибровку заново.

# [1.3.0](https://akprof2000.visualstudio.com/compare/v1.2.0...v1.3.0) (2026-06-27)

> 🌱💧 Новые возможности и стабильность: контроль засора фильтра, насос повышения
> давления, неблокирующая работа, отказ от динамической памяти (хеш-таблиц).
>
> ⚠️ **Внимание при обновлении:** изменился формат хранения настроек и пользователей.
> При первой прошивке однократно сбросятся сохранённые настройки/калибровка (SD) и
> список пользователей (EEPROM). После заливки: зажми кнопку сброса (обнулит
> пользователей) и зарегистрируйся заново по кодовому слову; калибровку датчиков
> пройди заново.

### ✨ Новые возможности (Features)

* **контроль фильтра:** обнаружение засора по падению скорости потока. Эталон «чистого»
  фильтра — по числу открытых клапанов (гибрид: авто-максимум + ручная рекалибровка
  кнопкой «🧽 Фильтр прочищен»). При падении ниже порога (по умолчанию 50 %) —
  уведомление в Telegram. Настраиваемый порог (`/ClogThreshold`, 10–90 %), статус
  в `/status`. Защита от ложных тревог: окно замера 30 с после выхода на режим,
  подтверждение по 3 окнам, лимит 1 сообщение в сутки, игнор сухого хода
* **насос повышения давления:** параметр `boostPumpValves` (1–8 — включать при ≥ N
  открытых клапанах, 9 — никогда). Настройка через меню `/BoostPump`

### ⚡ Производительность и стабильность (Performance)

* **отказ от хеш-таблиц:** управление пользователями переведено с `Hashtable<String,…>`
  на фиксированный массив `User users[8]`; состояние диалога (FSM) свёрнуто в поле
  `User::action`. Файл `hashtable.h` удалён из проекта. Устранён главный источник
  фрагментации кучи на длительном аптайме
* **неблокирующая работа:** убраны блокирующие `delay()` из рабочего цикла —
  ночная заливка бака (3 с), пролив дренажа (12 с) и переподключение WiFi (до 9 с)
  переведены на неблокирующие таймеры; бот и полив больше не «висят»

### 🐛 Исправления (Bug Fixes)

* **пользователи:** удаление пользователя теперь сохраняется в EEPROM (раньше терялось
  после перезагрузки)
* **уведомления:** флаг подписки на сообщения (`messages`) теперь сохраняется в EEPROM
* **EEPROM:** безопасное копирование ID пользователя (`strncpy` вместо `strcpy`)

# [1.2.0](https://akprof2000.visualstudio.com/compare/v1.1.0...v1.2.0) (2026-06-27)

> 🌱💧 Крупный рефакторинг прошивки: исправление логики полива, оптимизация работы
> с сетью и SD-картой, наведение порядка в коде без изменения поведения системы.

### 🐛 Исправления (Bug Fixes)

* **датчики:** `Percent()` теперь ограничивает влажность диапазоном `0–100 %`
  (`constrain`) и защищён от деления на ноль на некалиброванном канале
* **полив:** убран повторный опрос всех датчиков за цикл (экономия ~0.8 с блокировки)
* **расход воды:** запись литров на SD только при реальном потоке (счётчик импульсов
  изменился) — теперь корректно учитывается и пролив дренажа

### ⚡ Производительность (Performance)

* **NTP:** принудительная синхронизация не чаще раза в час; между ними время берётся
  локально из RTC/`millis()` — больше нет сетевого запроса при каждом открытии клапана
* **АЦП:** оверсэмплинг (усреднение 16 отсчётов) для стабильных показаний влажности;
  задержка переключения мультиплексора снижена `100 → 20 мс`
* **память:** сборка Telegram-сообщений в `checkValve` через `snprintf` вместо
  `String`-конкатенации — меньше фрагментации кучи при долгой работе

### ♻️ Рефакторинг (Refactoring)

* **архитектура:** `loop()` разбит на понятные функции (`handleBlink`, `checkWeather`,
  `controlValves`, `logToCsv`, `rotateLogFileIfNewDay`, `handlePumpTimeout`,
  `saveConfigIfDirty`) — основной цикл читается как оглавление
* **константы:** введён `NUM_CHANNELS` (единая точка правды) вместо литерала `8`
  во всех модулях, включая `telegram.cpp`
* **читаемость:** «магические числа» режимов и состояний заменены на именованные
  константы `Mode::{Auto,AlwaysOn,AlwaysOff,Greenhouse}` и `VState::{…}`
* **именование:** `init()` → `systemInit()` (устранено затенение функции ядра Arduino)
* **заголовки:** `#include "arduino.h"` → `<Arduino.h>` во всех файлах

# [1.1.0](https://akprof2000.visualstudio.com/compare/v1.0.1...v1.1.0) (2025-06-14)

### Features

* добавил полноеуправление клапанами мелкие багофиксы ([9951c19](https://akprof2000.visualstudio.com/commits/9951c19501788632a6bebdc4cf11c6703b1556e1))

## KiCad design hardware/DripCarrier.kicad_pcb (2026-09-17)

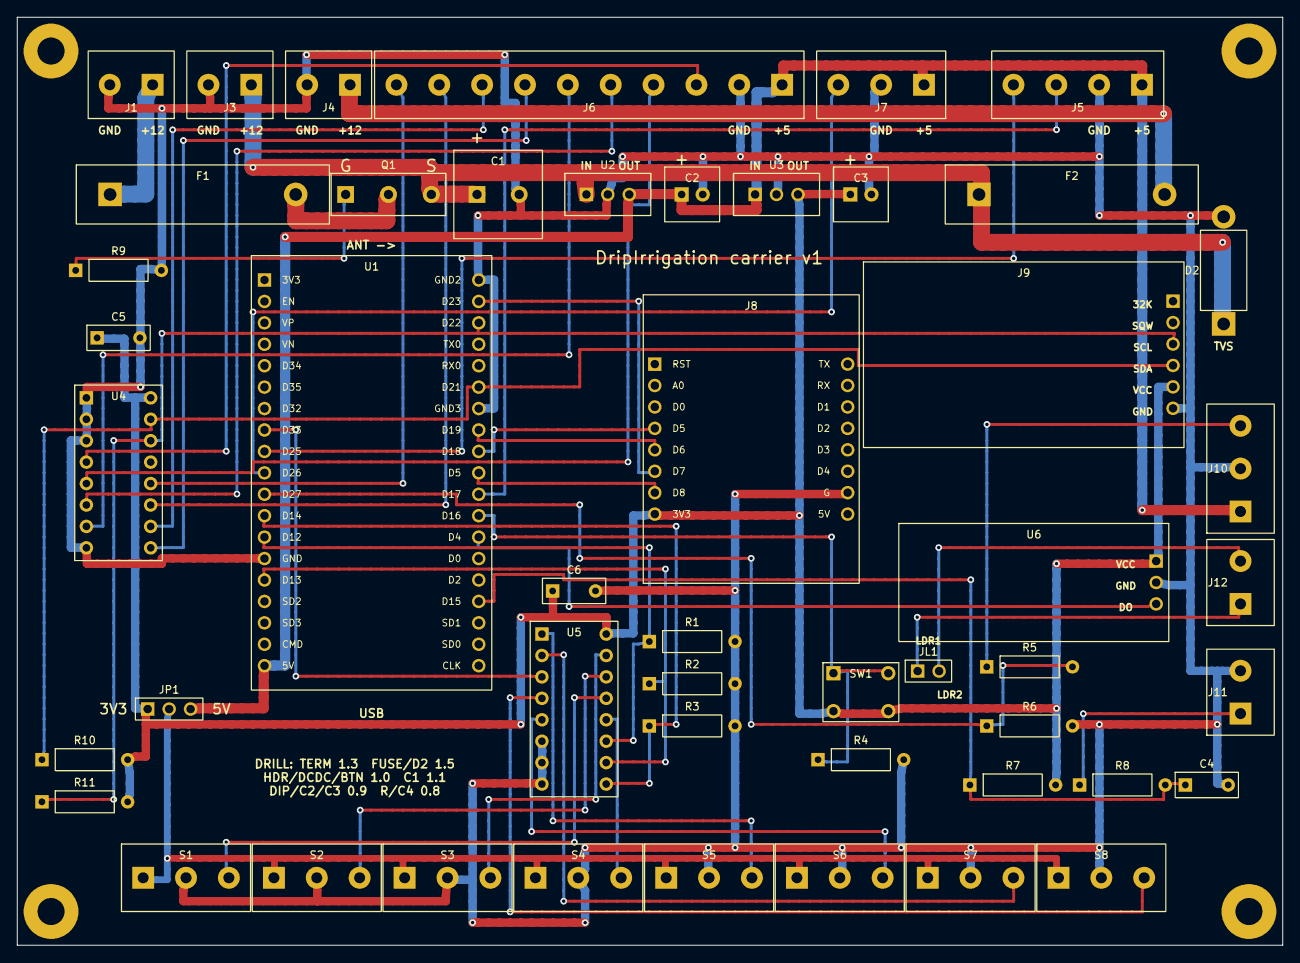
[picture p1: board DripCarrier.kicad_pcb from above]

Board: 2 copper layers, 150.0 x 110.0 mm, 53 parts (0 on the bottom side), 46 nets.

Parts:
C1: 1000u/16V; CAP_P5
C2, C3: 100u; CAP_P25
C4, C5, C6: 100n; CAP_C5
D2: P6KE18CA; DO201
F1: F1 5A; FUSE5x20
F2: F2 3A; FUSE5x20
H1, H2, H3, H4: M3; HOLE
J1: 12V IN; TERM2
J3: 12V VALVES; TERM2
J4: 12V PUMP; TERM2
J5: RELAY 2: +5 GND FILL DRAIN; TERM4
J6: RELAY 8: +5 GND IN1..IN8; TERM10
J7: RELAY 1: +5 GND PUMP; TERM3
J8: SD D1 mini; D1MINI
J9: DS3231; DS3231MOD
J10: FLOW; TERM3
J11: RAIN SW; TERM2
J12: LDR; TERM2
JL1: LDR; HDR1x2
JP1: 3V3 SENS 5V; JMP1x3
Q1: IRF4905; TO220_2
R1, R2, R3, R4, R5, R7, R9: 10k; R_AX
R6: 33k; R_AX
R8: 1k; R_AX
R10, R11: 4.7k; R_AX
S1: SOIL 1; TERM3
S2: SOIL 2; TERM3
S3: SOIL 3; TERM3
S4: SOIL 4; TERM3
S5: SOIL 5; TERM3
S6: SOIL 6; TERM3
S7: SOIL 7; TERM3
S8: SOIL 8; TERM3
SW1: RESET CFG; BTN6x6
U1: ESP32 DevKitC 38; ESP32_38
U2: DC-DC 12-5V 2A; TO220
U3: DC-DC 5-3.3V; TO220
U4: PCF8574P; DIP16
U5: 74HC4051; DIP16
U6: LIGHT LM393; LM393MOD

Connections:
12V_F: F1.2, Q1.2
12V_PUMP: F2.2, J4.1
12V_RAW: F1.1, J1.1
+3V3: C3.1, C5.1, C6.1, J8.3V3, J9.5, JP1.1, R7.2, R10.2, R11.2, SW1.3, SW1.4, U3.3, U4.16, U5.16, U6.1
+5V: C2.1, J5.1, J6.1, J7.1, J10.1, JP1.3, U1.5V, U2.3, U3.1
+12V: C1.1, D2.1, F2.1, J3.1, Q1.3, U2.1
ADC: U1.D33, U5.3
BTN: R4.1, SW1.1, SW1.2, U1.D16
DRAIN: J5.4, U1.D25
FILL: J5.3, U1.D17
FLOW: R5.2, R6.1, U1.D27
FLOW_IN: J10.3, R5.1
GND: C1.2, C2.2, C3.2, C4.2, C5.2, C6.2, D2.2, J1.2, J3.2, J4.2, J5.2, J6.2, J7.2, J8.G, J9.6, J10.2, J11.2, R1.2, R2.2, R3.2, R4.2, R6.2, R9.2, S1.2, S2.2, S3.2, S4.2, S5.2, S6.2, S7.2, S8.2, U1.GND, U1.GND2, U1.GND3, U2.2, U3.2, U4.1, U4.2, U4.3, U4.8, U5.6, U5.7, U5.8, U6.2
LDR_A: J12.1, JL1.1
LDR_B: J12.2, JL1.2
LIGHT: U1.D4, U6.3
P0: J6.3, U4.4
P1: J6.4, U4.5
P2: J6.5, U4.6
P3: J6.6, U4.7
P4: J6.7, U4.9
P5: J6.8, U4.10
P6: J6.9, U4.11
P7: J6.10, U4.12
PUMP: J7.3, U1.D26
QG: Q1.1, R9.1
RAIN: C4.1, R7.1, R8.2, U1.D15
RAIN_IN: J11.1, R8.1
S0: R1.1, U1.D12, U5.11
S1: R2.1, U1.D13, U5.10
S2: R3.1, U1.D14, U5.9
SCL: J9.3, R11.1, U1.D22, U4.14
SDA: J9.4, R10.1, U1.D21, U4.15
SD_CS: J8.D8, U1.D5
SD_MISO: J8.D6, U1.D19
SD_MOSI: J8.D7, U1.D23
SD_SCK: J8.D5, U1.D18
SENS_V: JP1.2, S1.1, S2.1, S3.1, S4.1, S5.1, S6.1, S7.1, S8.1
Y0: S1.3, U5.13
Y1: S2.3, U5.14
Y2: S3.3, U5.15
Y3: S4.3, U5.12
Y4: S5.3, U5.1
Y5: S6.3, U5.5
Y6: S7.3, U5.2
Y7: S8.3, U5.4

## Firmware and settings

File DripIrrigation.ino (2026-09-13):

#include "objects.h"
#include "telegram.h"
#include "init.h"
#include <esp_task_wdt.h>
#include "valves.h"
#include "irrigation.h"  // 🌱 чистая доменная логика решения о поливе
#include "log.h"
#include "faults.h"
#include <GyverNTP.h>

// GyverDS3231 поддерживает работу с GyverNTP
#include <GyverDS3231Min.h>
GyverDS3231Min rtc;

#define WDT_TIMEOUT 300  // ⏱️ Таймаут watchdog: 300 секунд (5 минут)

// 🕐 Поиск RTC: сколько попыток и с какой паузой. Ограниченное число попыток
//    вместо бесконечного ожидания — загрузка обязана дойти до botInit(),
//    иначе сообщить об аварии будет некому.
#define RTC_INIT_ATTEMPTS 3
#define RTC_INIT_RETRY_MS 300

// ⏱️ Таймер основного цикла проверки полива
unsigned long prevCheck = 0;
unsigned long intervalCheck = CHECK_INTERVAL;

// ============================================================
// 🚀 SETUP — Инициализация системы при включении питания
// ============================================================
void setup() {
  // 🛑 Первым делом — выходы реле в «выключено». До этого (портал до 3 мин, WiFi,
  //    SD) входы релейных модулей висели бы в воздухе и могли дребезжать.
  pinMode(PUMP, OUTPUT);  digitalWrite(PUMP, LOW);
  pinMode(DRAIN, OUTPUT); digitalWrite(DRAIN, LOW);
  pinMode(FILL, OUTPUT);  digitalWrite(FILL, LOW);

#if LOG_LEVEL > LOG_LEVEL_NONE
  Serial.begin(115200);  // 🖥️ UART нужен только при включённом логировании
#endif
  delay(1000);

  // 🔌 Инициализация шины I2C (нужна клапанам PCF8574 и RTC)
  Wire.begin();

  // 🌱 Инициализация модулей. Порядок важен: сначала железо, потом бот —
  //    тогда стартовое сообщение в чат уже знает, что именно не поднялось.
  //    Ни один из этих вызовов не блокирует загрузку: неответившая плата
  //    отмечается в реестре (faults.h), и мы идём дальше.
  systemInit();  // 📡 WiFi, EEPROM, SD, датчики
  valvesInit();  // 🚰 Клапаны через PCF8574

  // 🕐 Инициализация RTC (часы реального времени) — неблокирующая.
  //    Раньше здесь был бесконечный `while (!rtc.begin())`: без часов прошивка
  //    зависала до сброса, loop() не стартовал, бот молчал, и понять причину
  //    можно было, только подключившись к устройству.
  bool rtcOk = false;
  for (int attempt = 1; attempt <= RTC_INIT_ATTEMPTS; attempt++) {
    if (rtc.begin()) {
      rtcOk = true;
      break;
    }
    LOG_E("RTC не найден (попытка %d из %d)", attempt, RTC_INIT_ATTEMPTS);
    delay(RTC_INIT_RETRY_MS);
  }

  NTP.begin(3);  // 🌍 Запуск NTP с часовым поясом UTC+3 (Москва)

  // 🔗 Подключаем RTC к NTP для автоматической синхронизации
  if (rtcOk) {
    NTP.attachRTC(rtc);
  } else {
    hwSetFault(HW_RTC, "не отвечает на шине I2C");
  }

  botInit();  // 🤖 Telegram-бот — последним, чтобы сразу сообщить об авариях


  // 🔌 Настройка пинов датчиков и выходов
  //    Подтяжки задают состояние при оборванном кабеле: без света — «день»,
  //    без датчика дождя — «сухо», вместо случайных переключений раз в минуту.
  pinMode(LIGHT, INPUT_PULLDOWN);
  pinMode(RAIN, INPUT_PULLUP);

  // 🐕 Настройка Watchdog Timer
  LOG_I("Настройка watchdog (%d с)", WDT_TIMEOUT);
  esp_task_wdt_config_t twdt_config = {
    .timeout_ms = WDT_TIMEOUT * 1000,
    .idle_core_mask = 1,  // 🖥️ Маска ядер
    .trigger_panic = true,
  };

  esp_task_wdt_deinit();
  esp_task_wdt_init(&twdt_config);
  esp_task_wdt_add(NULL);
}

// ============================================================
// 📊 Глобальные переменные для отслеживания состояния
// ============================================================
int64_t oldTime = 0;  // ⏱️ Предыдущая минута (для записи в CSV)

bool oldNMode = false;  // 🌙 Предыдущее состояние ночного режима
bool oldRMode = false;  // 🌧️ Предыдущее состояние дождя

int oldM = 0;  // 📅 Предыдущий месяц
int oldD = 0;  // 📅 Предыдущий день
int oldY = 0;  // 📅 Предыдущий год

File dataFile;  // 💾 Текущий файл CSV для записи
String fn;      // 📁 Имя текущего файла данных

// 💡 Мигание LED (индикация работы)
const unsigned long blinkInt = 300;
unsigned long prevBlink = 0;
bool blink = false;

// 🚰 Неблокирующий импульс заливки бака (пин FILL)
unsigned long fillStart = 0;
bool fillActive = false;

// ============================================================
// 🚰 Проверка и управление конкретным клапаном
// ============================================================
// 📨 Презентация: формируем текст уведомления по новому состоянию клапана
static void formatValveEvent(char* buf, size_t n, int i, uint8_t state, int p) {
  const char* title = myConfig.chanel[i].title;
  int border = myConfig.chanel[i].border;
  switch (state) {
    case VState::OpenByHum:
      snprintf(buf, n, "🚰 Клапан № %d (%s) открыт по порогу влажности (%d %%), текущая влажность %d %%", i + 1, title, border, p);
      break;
    case VState::CloseByHum:
      snprintf(buf, n, "⛔ Клапан № %d (%s) закрыт по порогу влажности (%d %%), текущая влажность %d %%", i + 1, title, border, p);
      break;
    case VState::Hysteresis:
      snprintf(buf, n, "➖ Клапан № %d (%s) находится в промежуточном состоянии (%d %%), текущая влажность %d %%", i + 1, title, border, p);
      break;
    case VState::ForcedOpen:
      snprintf(buf, n, "✅ Клапан № %d (%s) открыт по настройке, текущая влажность %d %%", i + 1, title, p);
      break;
    case VState::ForcedClose:
      snprintf(buf, n, "⛔ Клапан № %d (%s) закрыт по настройке, текущая влажность %d %%", i + 1, title, p);
      break;
    default:
      buf[0] = '\0';
      break;
  }
}

// 🚰 Оболочка: получает чистое решение и применяет его (железо + уведомление)
void checkValve(int i) {
  int p = hs.Percent(i);  // 💧 Текущая влажность в процентах
  uint8_t mode = myConfig.chanel[i].mode;

  // 🖨️ Отладочный вывод порогов (только в авто/парнике, как и раньше)
  if (mode == Mode::Auto || mode == Mode::Greenhouse) {
    int b = myConfig.chanel[i].border;
    int d = myConfig.deltaHum;
    LOG_D("Канал %d: влажность %d%%, порог %d ±%d (%d..%d)",
          i, p, b, d, b - d, b + d);
  }

  // 🧠 Чистое решение (без побочных эффектов)
  ValveDecision dec = decideValve(mode, p, myConfig.chanel[i].border, myConfig.deltaHum, oldMode[i]);

  // ⚙️ Применяем действие к железу
  if (dec.action == ValveAction::Open) valveOpen(i);
  else if (dec.action == ValveAction::Close) valveClose(i);
  // ValveAction::Hold — ничего не делаем

  // 📨 Уведомление об изменении (заодно фиксируем новое состояние)
  if (dec.notify) {
    oldMode[i] = dec.newState;
    char msg[256];
    formatValveEvent(msg, sizeof(msg), i, dec.newState, p);
    LOG_I("%s", msg);
    sendTelegramStatus(msg);
  }
}

// ============================================================
// 💡 Мигание встроенным LED (индикация работы системы)
// ============================================================
static void handleBlink() {
  unsigned long now = millis();
  if (now - prevBlink >= blinkInt) {
    prevBlink = now;
    digitalWrite(LED_BUILTIN, blink ? HIGH : LOW);
    blink = !blink;
  }
}

// ============================================================
// 📁 Создание нового CSV-файла при наступлении нового дня
// ============================================================
static void rotateLogFileIfNewDay(Datime t) {
  if (oldY < t.year || oldM < t.month || oldD < t.day) {
    fn = "/" + String(t.year) + "/" + IntWith2Zero(t.month) + "/" + IntWith2Zero(t.day) + ".csv";
    SD.mkdir("/" + String(t.year));
    SD.mkdir("/" + String(t.year) + "/" + IntWith2Zero(t.month));

    if (!SD.exists(fn)) {
      LOG_I("Создаю файл данных: %s", fn.c_str());
      dataFile = SD.open(fn, FILE_WRITE);
      if (dataFile) {
        dataFile.println("UnixTime,DateTime,Index,Title,Humidity,Valve,Border,Night,Rain");
        dataFile.close();
      } else {
        LOG_E("Не создать файл %s", fn.c_str());
      }
    }
    oldY = t.year;
    oldM = t.month;
    oldD = t.day;
  }
}

// ============================================================
// 🚰 Запуск/завершение импульса заливки бака (без блокировки)
// ============================================================
static void startTankFill() {
  if (fillActive) return;  // 🔁 импульс уже идёт
  LOG_I("Старт заливки бака");
  digitalWrite(FILL, HIGH);
  fillStart = millis();
  fillActive = true;
  sendTelegramStatus("🚰 Старт заливки бака!");
}

static void handleTankFill() {
  if (fillActive && millis() - fillStart >= FILLING_WAIT) {
    digitalWrite(FILL, LOW);
    fillActive = false;
  }
}

// ============================================================
// 🌦️ Оценка погоды (дождь/ночь) + связанные уведомления
// ============================================================
static Weather checkWeather() {
  Weather w;

  // 🌧️ Проверка дождя
  if (digitalRead(RAIN) == LOW) {
    LOG_D("Дождь");
    if (!rainNow) {
      sendTelegramStatus("🌧️ Пошёл сильный дождь");
      rainNow = true;
    }
    if (!myConfig.runOnRain) {
      w.blocked = true;
      w.rainBlock = true;
      if (!oldRMode) {
        LOG_I("Дождь — отключаю полив");
        oldRMode = true;
        sendTelegramStatus("🌧️ Идёт дождь — отключаем полив!");
      }
    }
  } else {
    if (rainNow) {
      rainNow = false;
      sendTelegramStatus("☀️ Влажность после дождя достигла нормы");
    }
    if (oldRMode) {
      LOG_I("Дождь закончился — возобновляю полив");
      oldRMode = false;
      sendTelegramStatus("☀️ Восстановление работы после дождя!");
    }
  }

  // 🌙 Проверка ночи
  if (digitalRead(LIGHT) == HIGH) {
    LOG_D("Ночь");
    if (!nightNow) {
      nightNow = true;
      sendTelegramStatus("🌙 Наступила ночь");
    }
    if (!myConfig.runOnNight) {
      w.blocked = true;
      w.nightBlock = true;
      if (!oldNMode) {
        LOG_I("Ночь — энергосбережение");
        oldNMode = true;
        sendTelegramStatus("🌙 Переход в энергосберегающее состояние!");
        if (valveOpened() == true) {
          startTankFill();  // ⏱️ неблокирующий импульс заливки бака
        }
      }
    }
  } else {
    LOG_D("День");
    if (nightNow) {
      nightNow = false;
      sendTelegramStatus("☀️ Наступил день");
    }
    if (oldNMode) {
      LOG_I("День — возобновляю работу");
      oldNMode = false;
      sendTelegramStatus("☀️ Восстановление работы после ночного режима!");
      if (rainNow && !myConfig.runOnRain)
        sendTelegramStatus("🌧️ Погодная обстановка не достигла нормы!");
    }
  }

  return w;
}

// ============================================================
// 🚰 Управление всеми клапанами с учётом погодных блокировок
// ============================================================
static void controlValves(const Weather& w) {
  if (!w.blocked) {
    for (int i = 0; i < NUM_CHANNELS; i++) {
      checkValve(i);
    }
    return;
  }

  for (int i = 0; i < NUM_CHANNELS; i++) {
    // 🏠 В режиме парника или принудительно включён — поливаем даже при дожде (но не ночью)
    if (!w.nightBlock && w.rainBlock && (myConfig.chanel[i].mode == Mode::Greenhouse || myConfig.chanel[i].mode == Mode::AlwaysOn)) {
      checkValve(i);
    } else {
      valveClose(i);
      if (oldMode[i] != VState::ForcedClose) {
        oldMode[i] = VState::ForcedClose;
        char msg[160];
        snprintf(msg, sizeof(msg), "⛔ Клапан № %d (%s) закрыт", i + 1, myConfig.chanel[i].title);
        sendTelegramStatus(msg);
      }
    }
  }
}

// ============================================================
// 💾 Запись текущего состояния всех каналов в CSV
// ============================================================
static bool sdLost = false;   // 💾 карта недоступна — уведомление уже отправлено

static void logToCsv(Datime t, uint32_t curr) {
  LOG_D("Запись данных в CSV");
  dataFile = SD.open(fn, FILE_APPEND);
  if (dataFile) {
    for (int i = 0; i < NUM_CHANNELS; i++) {
      String row = String(curr) + ","
                   + t.toString(' ') + ","
                   + String(i + 1) + ","
                   + String(myConfig.chanel[i].title) + ","
                   + String(hs.Percent(i)) + ","
                   + String((oldMode[i] == VState::ForcedClose || oldMode[i] == VState::CloseByHum) ? 0 : 1) + ","
                   + String(myConfig.chanel[i].border) + ","
                   + String(nightNow ? 1 : 0) + ","
                   + String(rainNow ? 1 : 0);

      LOG_D("%s", row.c_str());
      dataFile.println(row);
    }
    dataFile.close();
    if (sdLost) {           // 💾 карта снова пишется — одно уведомление о восстановлении
      sdLost = false;
      connectCDCard();
    }
  } else {
    LOG_E("Не открыть файл для записи: %s", fn.c_str());
    if (!sdLost) {          // 💾 одно уведомление, а не 1440 в сутки
      sdLost = true;
      dropCDCard();
    }
  }
}

// ============================================================
// ⏱️ Защита насоса: автоотключение по таймауту работы
// ============================================================
static void handlePumpTimeout() {
  // ⏱️ Считаем по millis() — защита не зависит от синхронизации NTP/RTC.
  if (pumpStart != 0 && (millis() - pumpStart > (unsigned long)PUMP_TIMEOUT * 1000UL)) {
    LOG_W("Насос: завершён пусковой режим по таймауту (%d с)", PUMP_TIMEOUT);
    pumpStart = 0;
    stopPumpIfNeed();  // 💪 решает по boostPumpValves: оставить ВКЛ или выключить
  }
}

// ============================================================
// 🔧 Авто-калибровка границ датчиков влажности
// ============================================================
// Если показание устойчиво выходит за границу, заданную при калибровке (почва
// оказалась влажнее «воды» или суше «сухого»), граница отодвигается до этого
// значения с запасом в дельту калибровки. Границы только расширяются.
//
// 🛡️ Разовые выбросы АЦП игнорируются: граница двигается, только когда
// превышение держится HUM_AUTOCAL_CONFIRM минутных замеров подряд (см. sensors.h).
//
// ⛔ Работает ТОЛЬКО в режиме измерения: пока идёт диалог калибровки или поиска
// датчика, датчик держат в воде / на воздухе — такие показания нельзя принимать
// за рабочие, иначе авто-калибровка «выучит» калибровочные экстремумы.
static bool calibBoundsDirty = false;

static void autoCalibrateBounds() {
  if (calibrationInProgress()) return;

  // ⚡ «Без задержки» — двигаем границу по первому же отсчёту за ней;
  //    иначе ждём подтверждения HUM_AUTOCAL_CONFIRM замеров подряд.
  uint8_t confirm = myConfig.autoCalNoDelay ? 1 : HUM_AUTOCAL_CONFIRM;

  for (int i = 0; i < NUM_CHANNELS; i++) {
    if (hs.autoExtend(i, confirm)) {
      myConfig.chanel[i].minVal = hs.getLow(i);
      myConfig.chanel[i].maxVal = hs.getHigh(i);
      calibBoundsDirty = true;
      LOG_I("Канал %d: границы расширены до [%d; %d] (АЦП %d)",
            i + 1, hs.getLow(i), hs.getHigh(i), hs.getCurrent(i));
    }
  }
}

// ============================================================
// 💾 Сохранение конфигурации, если есть незаписанные изменения
// ============================================================
static void saveConfigIfDirty() {
  bool duv = valveNeedUpdate();
  bool dut = telegramNeedUpdate();
  bool duf = flowMonitorNeedUpdate();  // 🧽 обновился эталон фильтра
  bool duc = calibBoundsDirty;         // 🔧 авто-расширены границы калибровки
  calibBoundsDirty = false;
  if (duv || dut || duf || duc) {
    data.update();
  }
}

// ============================================================
// 🛑 Гашение нагрузок при переходе в аварийный режим
// ============================================================
// Вызывается из loop() на каждой итерации, но работу делает один раз: важно
// не оставить открытым клапан или включённым насос, если авария случилась
// посреди полива. Закрытие клапанов — «по возможности»: если не поднялся сам
// PCF8574, команда не дойдёт, поэтому реле насоса и дренажа гасим напрямую
// по пинам, не полагаясь на расширитель портов.
static bool faultShutdownDone = false;

static void faultSafeShutdown() {
  if (faultShutdownDone) return;
  faultShutdownDone = true;

  LOG_W("Аварийный режим: гашу нагрузки, полив остановлен");
  // 🛑 loadsOff() сначала сбрасывает pumpStart и пишет в PCF8574 (даже если он
  //    помечен неисправным — попытка стоит миллисекунд), и только потом гасит пины:
  //    иначе закрытие клапана через stopPumpIfNeed() снова включало бы насос.
  loadsOff();
}

// ============================================================
// 🔄 ГЛАВНЫЙ ЦИКЛ LOOP
// ============================================================
void loop() {
  handleBlink();      // 💡 индикация работы
  ReCheck();          // 🤖 Telegram + проверка WiFi
  telegramGzOtaTick(); // 🗜️ отложенная распаковка+прошивка .gz (после tick)

  // 🆘 Аварийный режим: какая-то плата не поднялась при старте.
  //    Полив не ведём — без часов расписание бессмысленно, без карты некуда
  //    писать журнал, без PCF8574 клапанами вообще не управлять. Зато бот и
  //    watchdog живут: в чате виден список неисправностей, а кнопка
  //    «Перезагрузка» позволяет поднять систему, не подключаясь кабелем.
  if (hwHasFault()) {
    faultSafeShutdown();   // 🛑 один раз гасим нагрузки
    hwReportToChat();      // 📨 отчёт в чат (если при старте связи ещё не было)
    esp_task_wdt_reset();  // 🐕 иначе watchdog уронит устройство через 5 минут
    return;
  }

  handleTankFill();   // ⏱️ неблокирующий импульс заливки бака
  spillageTick();     // ⏱️ неблокирующий пролив дренажа
  handlePumpTimeout(); // ⏱️ завершение пускового режима насоса (каждый loop, по millis)
  flowMonitorTick();  // 🧽 контроль засора фильтра по скорости потока

  unsigned long now = millis();
  if (now - prevCheck < intervalCheck) return;  // ⏱️ ещё не пора — выходим
  prevCheck = now;

  Datime t = getDateTime();
  uint32_t curr = t.getUnix();

  // 📅 Основная логика полива и логирование — раз в минуту
  // ⏰ «!=», а не «<»: при откате часов назад (первая синхронизация NTP после
  //    неверного RTC) полив и журнал иначе замирали бы, пока время не догонит.
  if (oldTime != int64_t(curr / 60)) {
    flowGetSessionLitersTick();
    rotateLogFileIfNewDay(t);
    oldTime = int64_t(curr / 60);

    LOG_D("Проверка состояния");
    hs.setAll();          // 💧 Опрос всех датчиков влажности
    autoCalibrateBounds(); // 🔧 расширить границы, если показания вышли за диапазон

    Weather w = checkWeather();
    controlValves(w);
    logToCsv(t, curr);
  }

  saveConfigIfDirty();      // 💾 отложенное сохранение конфига
  esp_task_wdt_reset();     // 🐕 сброс watchdog
}

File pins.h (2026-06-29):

// pins.h 📌 Назначение пинов ESP32 (аппаратная карта проекта)
#pragma once

#define PIN_SPI_CS 5            // 💾 CS SD-карты

const int LED_BUILTIN = 2;     // 💡 Встроенный светодиод
const int BUTTON = 16;         // 🔘 Кнопка сброса настроек
const int LIGHT = 4;           // ☀️ Датчик освещённости (день/ночь)
const int RAIN = 15;           // 🌧️ Датчик дождя
const int FILL = 17;           // 🚰 Клапан наполнения бака
const int DRAIN = 25;          // 🗑️ Клапан слива (дренаж)
const int PUMP = 26;           // ⚡ Реле насоса
const int FLOW_SENSOR = 27;    // 💧 Датчик потока воды (расходомер)

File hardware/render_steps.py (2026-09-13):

#!/usr/bin/env python3
# -*- coding: utf-8 -*-
"""
Картинки этапов сборки: для каждого шага оставляет в копии платы только 3D-модели
деталей, уже установленных к этому шагу, и рендерит плату в KiCad 10 (Docker).
Запуск:  python hardware/render_steps.py   ->  docs/assembly/step-NN.png
"""
import os, re, shutil, subprocess

HW = os.path.dirname(os.path.abspath(__file__))
OUT = os.path.join(os.path.dirname(HW), 'docs', 'assembly')
IMG = 'kicad/kicad:10.0.5-full'

# Шаги: какие позиции появляются. Для гнёзд модулей и панелек отдельно указано,
# ставится ли только гнездо ('socket') или модуль/микросхема ('module').
STEPS = [
    ('01', ['R1', 'R2', 'R3', 'R4', 'R5', 'R6', 'R7', 'R8', 'R9', 'R10', 'R11', 'D2']),
    ('02', ['C4', 'C5', 'C6', 'SW1', 'JP1:socket', 'JL1']),
    ('03', ['U4:socket', 'U5:socket']),
    ('04', ['U1:socket', 'J8:socket', 'J9:socket', 'U6:socket']),
    ('05', ['C1', 'C2', 'C3', 'U2', 'U3', 'Q1']),
    ('06', ['F1', 'F2']),
    ('07', ['J1', 'J3', 'J4', 'J5', 'J6', 'J7', 'J10', 'J11', 'J12'] + ['S%d' % i for i in range(1, 9)]),
    ('08', ['U4:module', 'U5:module', 'JP1:module']),
    ('09', ['U1:module', 'J8:module', 'J9:module', 'U6:module']),
]
MODULE_MODELS = ('esp32_devkitc_38', 'd1mini_sd', 'ds3231', 'lm393_light', 'jumper', 'DIP-16_W7.62mm.step')


def footprints(text):
    """Возвращает список (start, end, ref) для каждого footprint верхнего уровня."""
    res, i = [], 0
    while True:
        j = text.find('(footprint ', i)
        if j < 0:
            return res
        d, k = 0, j
        while True:
            ch = text[k]
            if ch == '(':
                d += 1
            elif ch == ')':
                d -= 1
                if d == 0:
                    break
            k += 1
        block = text[j:k + 1]
        m = re.search(r'\(property "Reference" "([^"]+)"', block)
        res.append((j, k + 1, m.group(1) if m else ''))
        i = k + 1


def strip_models(block, keep):
    """keep: None — удалить все модели; 'socket' — оставить только гнёзда; 'all' — всё."""
    if keep == 'all':
        return block
    out, i = [], 0
    while True:
        j = block.find('(model ', i)
        if j < 0:
            out.append(block[i:])
            return ''.join(out)
        d, k = 0, j
        while True:
            ch = block[k]
            if ch == '(':
                d += 1
            elif ch == ')':
                d -= 1
                if d == 0:
                    break
            k += 1
        model = block[j:k + 1]
        is_module = any(n in model for n in MODULE_MODELS)
        drop = keep is None or (keep == 'socket' and is_module)
        out.append(block[i:j])
        if not drop:
            out.append(model)
        i = k + 1


def main():
    src = open(os.path.join(HW, 'DripCarrier.kicad_pcb'), encoding='utf-8').read()
    fps = footprints(src)
    os.makedirs(OUT, exist_ok=True)
    installed = {}
    work = os.path.join(HW, '_steps')
    shutil.rmtree(work, ignore_errors=True)
    os.makedirs(work)
    # модели модулей подключены как ${KIPRJMOD}/3d/..., а KIPRJMOD копии — это папка _steps
    shutil.copytree(os.path.join(HW, '3d'), os.path.join(work, '3d'))
    cmds = []
    for num, parts in STEPS:
        for p in parts:
            ref, _, stage = p.partition(':')
            installed[ref] = 'socket' if stage == 'socket' else 'all'
        pieces, pos = [], 0
        for a, b, ref in fps:
            pieces.append(src[pos:a])
            pieces.append(strip_models(src[a:b], installed.get(ref)))
            pos = b
        pieces.append(src[pos:])
        name = 'step-%s' % num
        open(os.path.join(work, name + '.kicad_pcb'), 'w', encoding='utf-8').write(''.join(pieces))
        shutil.copy(os.path.join(HW, 'DripCarrier.kicad_pro'), os.path.join(work, name + '.kicad_pro'))
        cmds.append("kicad-cli pcb render --quality high --floor --perspective --rotate '-50,0,20' --zoom 1.15 "
                    "--width 1600 --height 1100 -o /out/%s.png _steps/%s.kicad_pcb >/dev/null" % (name, name))
    hw_win, out_win = os.path.abspath(HW), os.path.abspath(OUT)   # Windows-пути понимает и Docker Desktop, и Git Bash
    env = dict(os.environ, MSYS_NO_PATHCONV='1')
    r = subprocess.run(['docker', 'run', '--rm', '-u', '0', '-v', hw_win + ':/hw', '-v', out_win + ':/out', '-w', '/hw',
                        IMG, 'sh', '-c', ' && '.join(cmds)], env=env)
    shutil.rmtree(work, ignore_errors=True)
    print('rc', r.returncode, sorted(os.listdir(OUT)))


if __name__ == '__main__':
    main()

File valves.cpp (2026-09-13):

// valves.cpp 🚰 Модуль управления клапанами через PCF8574
#include "valves.h"
#include <Wire.h>
#include <PCF8574.h>
#include "objects.h"
#include "log.h"
#include "faults.h"  // 🩺 регистрация аварии, если плата не отвечает

// 🔁 Попытки поднять плату клапанов при старте (неблокирующе)
#define PCF_INIT_ATTEMPTS 3
#define PCF_INIT_RETRY_MS 300

// 🔌 Экземпляр расширителя портов PCF8574 (адрес 0x20)
PCF8574 pcf8574(0x20);

// 🚰 Флаг открытия клапана (для насоса)
bool isOpen = false;

// ⛔ Состояния клапанов (true = закрыт)
bool isClose[NUM_CHANNELS] = { true, true, true, true, true, true, true, true };

// 🔄 Флаг необходимости сохранения конфигурации
bool needValveUpdate = false;

// ============================================================
// 🚰 Проверить и сбросить флаг открытия клапана
// ============================================================
bool valveOpened() {
  bool opn = isOpen;
  isOpen = false;
  return opn;
}

// ============================================================
// 🔌 Инициализация PCF8574 и всех пинов как OUTPUT
// ============================================================
void valvesInit() {
  pcf8574.pinMode(P0, OUTPUT);
  pcf8574.pinMode(P1, OUTPUT);
  pcf8574.pinMode(P2, OUTPUT);
  pcf8574.pinMode(P3, OUTPUT);
  pcf8574.pinMode(P4, OUTPUT);
  pcf8574.pinMode(P5, OUTPUT);
  pcf8574.pinMode(P6, OUTPUT);
  pcf8574.pinMode(P7, OUTPUT);

  // 🔌 Неблокирующая инициализация: несколько попыток и идём дальше. Без платы
  //    клапанами управлять нечем, поэтому отмечаем аварию — бот сообщит о ней
  //    в чат и свернётся до кнопки перезагрузки.
  bool ok = false;
  for (int attempt = 1; attempt <= PCF_INIT_ATTEMPTS; attempt++) {
    if (pcf8574.begin() == 1) { ok = true; break; }
    LOG_E("PCF8574 не отвечает (попытка %d из %d)", attempt, PCF_INIT_ATTEMPTS);
    delay(PCF_INIT_RETRY_MS);
  }

  if (ok) {
    LOG_I("Клапаны (PCF8574) инициализированы");
  } else {
    hwSetFault(HW_VALVES, "не отвечает на шине I2C");
  }
}

// ============================================================
// 🗑️ Пролив дренажа: наполнение + слив
// ============================================================
// 🗑️ Неблокирующий пролив: spillage() запускает, spillageTick() завершает по таймеру
static bool drainActive = false;
static unsigned long drainStart = 0;

void spillage() {
  if (drainActive) return;  // 🔁 уже идёт — не перезапускаем
  LOG_I("Запуск пролива дренажа");
  sendTelegramStatus("🗑️ Запуск пролива дренажа");
  digitalWrite(DRAIN, HIGH);
  digitalWrite(PUMP, HIGH);
  drainStart = millis();
  drainActive = true;
}

// 🗑️ Идёт ли сейчас пролив дренажа
bool valveIsDraining() {
  return drainActive;
}

// ⏱️ Завершение пролива по истечении DRAIN_TIMEOUT — вызывать в каждом цикле loop()
void spillageTick() {
  if (drainActive && (millis() - drainStart >= DRAIN_TIMEOUT)) {
    digitalWrite(DRAIN, LOW);
    drainActive = false;
    stopPumpIfNeed();
    sendTelegramStatus("✅ Пролив дренажа завершён");
    LOG_I("Пролив дренажа завершён");
  }
}

// ============================================================
// 🚰 Открыть клапан по индексу
// ============================================================
void valveOpen(int index) {
  pcf8574.digitalWrite(index, LOW);  // 🔌 LOW = открыть (инверсная логика реле)
  isOpen = true;

  // ⚡ Если клапан был закрыт — включаем насос
  if (isClose[index]) {
    LOG_D("Клапан %d открыт, насос ВКЛ", index + 1);
    digitalWrite(PUMP, HIGH);
    pumpStart = millis();
    if (pumpStart == 0) pumpStart = 1;  // 0 зарезервирован под «не в пусковом режиме»

    // 💧 Проверяем, был ли кто-то из клапанов уже открыт (для сброса счётчика расхода)
    bool anyOpen = false;
    for (int i = 0; i < NUM_CHANNELS; i++) {
      if (!isClose[i]) {
        anyOpen = true;
        break;
      }
    }
    // 🔄 Если до этого все клапаны были закрыты — начинаем новую сессию замера расхода воды
    if (!anyOpen) {
      flowResetSession();
    }
  }
  isClose[index] = false;

  // 🗑️ Если все клапаны были закрыты долго — делаем пролив
  if (myConfig.utimeAllClosed != 0) {
    unsigned long ut = getDateTime().getUnix();
    // ⏰ ut > utimeAllClosed: при откате часов (первая NTP-синхронизация) беззнаковая
    //    разность иначе переполнится и запустит ложный пролив
    if (ut > myConfig.utimeAllClosed && ut - myConfig.utimeAllClosed > TIMEOUT_WAIT) {
      spillage();
    }
    myConfig.utimeAllClosed = 0;
    needValveUpdate = true;
  }
}

// ============================================================
// ⛔ Закрыть клапан по индексу
// ============================================================
void valveClose(int index) {
  if (!isClose[index]) LOG_D("Клапан %d закрыт", index + 1);
  pcf8574.digitalWrite(index, HIGH);  // 🔌 HIGH = закрыть
  isClose[index] = true;

  // 💪 Пересчитать состояние насоса (пусковое окно и дренаж учитывает сам хелпер)
  stopPumpIfNeed();

  // ⏱️ Проверяем, все ли клапаны закрыты
  bool allCls = true;
  for (int i = 0; i < NUM_CHANNELS; i++) {
    if (!isClose[i]) {
      allCls = false;
      break;
    }
  }

  // ⏱️ Фиксируем время закрытия всех клапанов (для пролива)
  if (allCls) {
    if (myConfig.utimeAllClosed == 0) {
      myConfig.utimeAllClosed = getDateTime().getUnix();
      needValveUpdate = true;

      // 💧 Все клапаны закрыты — фиксируем расход воды за сессию
      flowAddToTotal();
    }
  }
}


void stopPumpIfNeed() {

  if (drainActive) return;  // 🗑️ во время пролива дренажа насос держим включённым

  // ⏱️ Пусковой режим: после открытия клапана насос обязан работать минимум
  // PUMP_TIMEOUT секунд (pumpStart обнуляет handlePumpTimeout в основном цикле,
  // после чего решает порог ниже). Без этой проверки завершение пролива дренажа
  // (spillageTick) или смена настройки boostPumpValves выключали насос раньше
  // времени — типичный случай: после перезагрузки первое открытие клапана
  // запускало пролив, и его завершение глушило насос на 12-й секунде.
  if (pumpStart != 0) {
    digitalWrite(PUMP, HIGH);
    return;
  }

  // 💪 Насос повышения давления: при пороге N=1..8 держим насос включённым,
  // пока открыто N и более клапанов; иначе (или N=9 — выкл) — останавливаем.
  uint8_t n = myConfig.boostPumpValves;
  bool on = (n >= 1 && n <= NUM_CHANNELS && countValveOpen() >= n);
  digitalWrite(PUMP, on ? HIGH : LOW);

  // 📝 Логируем только смену состояния насоса (без спама каждый цикл)
  static int8_t lastPump = -1;
  if ((int8_t)on != lastPump) {
    lastPump = on;
    LOG_D("Насос: %s (открыто %d кл., порог %d)", on ? "ВКЛ" : "ВЫКЛ", countValveOpen(), n);
  }
}

// 💪 Фактическое состояние насоса — читаем уровень пина реле
bool pumpIsOn() {
  return digitalRead(PUMP) == HIGH;
}

int countValveOpen() {
  int cnt = 0;
  for (int i = 0; i < NUM_CHANNELS; i++) {
    if (isClose[i] == false)
      cnt++;
  }
  return cnt;
}
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

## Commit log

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2023-07-01 fix: ошибка полной инициализации, идинтефикация режимов, сдвиг при переходе
    [DripIrrigation.ino]
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2023-07-23 fix: добавил вотч дог, а то повисает
    [DripIrrigation.ino]
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2024-04-22 bug fix delta hum
    [DripIrrigation.ino]
2024-04-23 vug fix timeout WDT
    [DripIrrigation.ino]
2024-05-11 fix rain variable, add enable / disable valve now on config
    [DripIrrigation.ino, valves.cpp]
2024-05-14 fix WDT, fix write to file, change menu reports
    [DripIrrigation.ino, init.cpp, objects.h]
2024-05-30 fix by new version arduino ide and esp32
    [DripIrrigation.ino, init.cpp, sensors.h]
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2024-06-09 change reset to start
    [DripIrrigation.ino]
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2026-06-29 Refactor to modular architecture + new features (boost pump, filter, logging)
    Архитектура и чистка:
    - Разбиение god-файлов на модули: irrigation, users, botutil, bot_transport, reports, log, pins.h, timing.h, secrets.h
    - Hashtable<String,...> (пользователи + FSM диалогов) заменены на фикс-массивы (без фрагментации кучи); удалены hashtable.h, мёртвый logger, listDir
    - Полив: функциональное ядро / оболочка (decideValve)
    - Единый camelCase; enum Mode::/VState::/Dlg:: вместо магических чисел
    Новые возможности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
2026-06-30 Контроль фильтра: расчёт «на клапан», отдельный дренаж и корректная калибровка
    Пересмотрена модель оценки засора фильтра по скорости потока:
    - Эталон теперь PER-VALVE (cleanFlowPerValve) вместо массива по числу
    открытых клапанов. Ожидаемый поток = скорость_клапана × N_открытых.
    Исправлен ложный «засор» при малом числе открытых клапанов.
    - Пролив дренажа вынесен в отдельный эталон (cleanFlowDrain) и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
    [objects.h]
2026-06-30 Насос: защита по millis + поток в статусе обновляется всегда
    Исправлены две связанные регрессии (насос не выключался → поток в /status был 0):
    - Защита насоса по таймауту переведена с unix-времени на millis().
    При несинхронных RTC/NTP unix-время не росло, таймаут не срабатывал
    и насос оставался включённым. millis() монотонен и не зависит от
    синхронизации часов. Те же 30 с, stopPumpIfNeed() не изменён.
    - handlePumpTimeout(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
    [DripIrrigation.ino, objects.h, valves.cpp]
2026-07-01 Аудит качества кода: переполнение буфера, выход за границы массивов, мёртвый код
    Полный проход по проекту на предмет логических ошибок и качества кода:
    - telegram.cpp: strcpy при переименовании датчика переполнял title[90] от
    произвольного текста Telegram (до 4096 байт), портя соседние поля Config —
    заменён на strncpy с обрезкой; заодно вырезаются запятая/перевод строки
    (ломают CSV-лог) и < > & (ломают HTML-реж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
2026-07-01 Контроль фильтра: адаптивное ожидание вместо фиксированной паузы
    При открытии клапана пустая труба наполняется, и поток кратковременно
    завышен (гидроудар/заполнение воздуха водой), потом падает до реального.
    Фиксированные 5 секунд settle этого не покрывали — всплеск попадал в окно
    замера и калибровался как «эталон чистого фильтра», давая затем ложные
    тревоги о засоре.
    Вместо фикс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
2026-07-01 Контроль фильтра: жёсткий минимум ожидания 10 мин перед проверкой стабилизации
    По факту с боевого стенда: пролив поднялся до 4 л/мин и плавно (без резких
    скачков между 20-секундными подынтервалами) упал до 1 л/мин — детектор
    стабилизации ложно решил, что поток устаканился, зафиксировал завышенный
    эталон, и дальнейшее плавное снижение было принято за засор фильтра.
    Плавный спад на да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
2026-07-01 Контроль фильтра: разовый выброс потока не должен сразу становиться эталоном
    Авто-обучение эталона «на клапан» брало максимум за одно измерительное окно
    (30 с) как новое значение — единичный выброс (пузырь воздуха, наводка на
    датчике потока) сразу фиксировался как «чистый» эталон навсегда, занижая
    порог тревоги о засоре на будущее.
    Повышенное значение теперь становится кандидат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
2026-07-02 Рефакторинг: единый показ меню бота + чистка контроля потока
    telegram.cpp:
    - Добавлен showMenu(): в контексте callback-кнопки редактирует сообщение
    (editText), в текстовом контексте отправляет новое. Исправлен системный
    баг: все меню делали editText безусловно, и после текстового ответа
    (Да/Нет, ввод числа) меню молча не показывалось — /Calibrate, /Users,
    /Namings, /Borders, /OperationMode, /Graphics и др.
    - Слиты дублирующиеся пар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
2026-07-02 Насос: пусковой режим не прерывается проливом дренажа
    После перезагрузки первое открытие клапана запускало пролив дренажа
    (utimeAllClosed хранится на SD и после ребута «старый»), а его завершение
    через 12 с вызывало stopPumpIfNeed(), который смотрел только на порог
    boostPumpValves и глушил насос — хотя пусковой режим обязан держать насос
    минимум PUMP_TIMEOUT (30 с) после открытия клапана.
    stopPumpIfNeed() теперь уваж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
2026-07-02 Добавлены README, LICENSE (GPL-3) и схемы из прежнего GitHub-репозитория
    Инструкция про токен обновлена под secrets.h (токен больше не хранится в коде).
2026-07-02 README и схемы: датчик потока, новые SVG-схемы, актуализация меню
    - Схема подключения перерисована с нуля в SVG: цветовые шины (I2C, SPI,
    аналог, импульсы), легенда, актуальная разводка пинов из pins.h/sensors.h
    (на старой PNG мультиплексор сидел на GPIO25/26/27, давно занятых
    дренажом, насосом и датчиком потока). Добавлен датчик потока YF-S201.
    - Блок-схема алгоритма перерисована: основной минутный цикл + пане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
2026-07-02 Схемы: устранены наложения подписей; README: инструкция по боту
    Схемы (проверено рендером в headless Chrome):
    - draw.svg: подписи SDA/SCL сняты с вертикальных проводов и размещены
    на горизонтальных сегментах шины; SD-блок укорочен (подпись налезала
    на MOSI); подпись мультиплексора вынесена под блок.
    - block.svg: пунктир возврата к началу больше не проходит сквозь блок
    «Открыть клапан»; подписи ветвей «ни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
2026-07-03 Статус насоса в /status + профессиональный README с диаграммами процессов
    Прошивка:
    - /status показывает блок «Насос давления»: фактическое состояние пина
    реле (pumpIsOn) и причину — пусковой режим / порог открытых клапанов /
    пролив дренажа / выключен, плюс текущая настройка boostPumpValves.
    README (полная переработка):
    - Три новые SVG-диаграммы процессов (проверены рендером): гистерезис
    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
2026-08-07 fix(flow): замер потока на капельных расходах + диагностика датчика
    Окно замера 30 с с порогом 40 импульсов давало отсечку 0.18 л/мин —
    любой реальный капельный полив уходил в ветку «сухой ход», и контроль
    фильтра не работал. Окно 120 с, порог 10 импульсов → отсечка 0.011 л/мин.
    Подынтервал ожидания стабилизации 20 с давал шаг квантования ~14 % при
    пороге стабильности 10 % — детектор срабатывал на ш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
    [objects.h]
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2026-09-13 feat(hardware): плата-носитель из готовых модулей и документация
    Генератор печатной платы 150×110 мм (gen_pcb.py) с проверкой пересечений
    и трассировкой, проект KiCad, 3D-модели модулей, скрипты проверки DRC и
    выгрузки Gerber через KiCad 10 в Docker, рендеры этапов сборки.
    Документация: описание платы, список покупок, пошаговая сборка.
    Собранные файлы (Gerber, рендеры, отчёт DRC, HTML-версии) не коммитятся.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
    [DripCarrier.kicad_pcb]
2026-09-13 fix(hardware): ревизия платы, скриптов и документации
    Схема:
    - кнопка сброса: R4 теперь тянет GPIO16 к земле, кнопка замыкает на 3,3 В (как ждёт прошивка)
    - защита от переполюсовки: P-MOSFET IRF4905 (Q1, R9) вместо диода 1N5822 — без нагрева при 5 А
    - TVS P6KE18CA (D2) на шине 12 В, развязка C5/C6, подтяжки I2C R10/R11
    - делитель расходомера R6 20k→33k (учтена внутренняя подтяжка YF-S201)
    - 3V3 модуля ESP32 отвязан от шины 3,3 В (два стабилизатор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
    [DripCarrier.kicad_pcb]
2026-09-13 fix(hardware): подписи полярности клемм, квадратные площадки в SVG, концы дорожек в центрах площадок
    [DripCarrier.kicad_pcb]
2026-09-13 fix(firmware): ревизия прошивки — 17 находок, v1.10.0
    См. CHANGELOG 1.10.0: транспорт Telegram не блокирует loop при ошибках API,
    UTF-8-безопасная обрезка названий, портал строит страницу заново, пароль WiFi
    до 63 символов с миграцией EEPROM, защита регистрации владельца, устойчивость
    к откату часов, loadsOff() перед перезагрузкой и в аварии, выходы реле с первой
    строки setup(), подтяжки входов, одно уведомление об SD, проверк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
    [DripIrrigation.ino, build_viewer.py, init.cpp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]
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2026-09-17 feat(hardware): подписи выводов гнёзд J9, U6 и штырей JL1 на шелкографии
    [DripCarrier.kicad_pcb]
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
